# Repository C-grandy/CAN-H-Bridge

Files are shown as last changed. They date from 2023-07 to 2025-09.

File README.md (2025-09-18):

# CAN-H-Bridge
A CAN Bus controlled H-Bridge motor driver designed for 12V, 10-20A brushed motors with encoders. Features a Atmel Atmega328 MCU along with a MCP2515 CAN controller for compatability with Arduino or standalone AVR C. 
NOTE: This design should not be used as is, it has a few design flaws as it was a proof of concept that was never developed further. 
## Circuit Overview
The design has two major parts, the controls and the H-Bridge motor driver. 
### Controls
The heart of the control system is the Atmega328 MCU. This MCU communicates over CAN for connectivity to other devices along with sending the appropriate PWM and enable signals to the H-bridge driver. It has connectors for a 2 pin quadrature encoder, specifically designed with GoBilda Yellow Jacket gear motors in mind. 


### Driver
The driver features 2 IRS2104's half-bridge gate drivers to drive the IRF3205 MOSFETS. This is a standard H-bridge setup, with adequete protection for expected loads. 
NOTE: This circuit uses a external 12V refrence for the IRS2104 input voltage, do not exceed 12V on board VCC or the driver might not work correctly. This is a major design flaw in the circuit as it should include a isolated supply that is refrenced off of VCC. 


## PCB Layout:
This board is a 2 layer stackup, with very basic PCB design rules followed. The overall design of the PCB is lacking, the traces are not properly sized for the loads at hand and a lack of copper pours makes this a elementary design. Even with these shortcomings, the PCB works as expected, but in long tests proved it needed refinement. 

Front: 


Back: 


### 3D Render: 

Front:



Back:



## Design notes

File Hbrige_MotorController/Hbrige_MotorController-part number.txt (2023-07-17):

"Source:","C:\Users\rober\Desktop\Hbrige_MotorController\Hbrige_MotorController.kicad_sch"
"Date:","7/16/2023 10:04:55 PM"
"Tool:","Eeschema (6.0.8)"
"Generator:","D:\KiCad\6.0\bin\scripting\plugins/bom_csv_grouped_by_value.py"
"Component Count:","62"

"Individual Components:"

"Item","Qty","Reference(s)","Value","LibPart","Footprint","Datasheet"

"","","D11","LED_G","Device:LED","LED_SMD:LED_0603_1608Metric_Pad1.05x0.95mm_HandSolder","~"
"","","D12","LED_R","Device:LED","LED_SMD:LED_0603_1608Metric_Pad1.05x0.95mm_HandSolder","~"

"","","J1","Conn_01x05_Female","Connector:Conn_01x05_Female","Connector_JST:JST_XH_B5B-XH-A_1x05_P2.50mm_Vertical","~"
"","","J2","Conn_01x04_Female","Connector:Conn_01x04_Female","Connector_JST:JST_XA_B04B-XASK-1-A_1x04_P2.50mm_Vertical","~"
"","","J3","Conn_01x04_Female","Connector:Conn_01x04_Female","Connector_JST:JST_XA_B04B-XASK-1-A_1x04_P2.50mm_Vertical","~"
"","","J4","Conn_02x03_Odd_Even","Connector_Generic:Conn_02x03_Odd_Even","Connector_PinHeader_2.54mm:PinHeader_2x03_P2.54mm_Vertical","~"
"","","J5","Screw_Terminal_01x02","Connector:Screw_Terminal_01x02","TerminalBlock:TerminalBlock_Altech_AK300-2_P5.00mm","~"

"","","M1","Motor_DC","Motor:Motor_DC","TerminalBlock:TerminalBlock_Altech_AK300-2_P5.00mm","~"

"","","Q1","IRF3205","Transistor_FET:IRF3205","Package_TO_SOT_THT:TO-220-3_Horizontal_TabDown","http://www.irf.com/product-info/datasheets/data/irf3205.pdf"
"","","Q2","IRF3205","Transistor_FET:IRF3205","Package_TO_SOT_THT:TO-220-3_Horizontal_TabDown","http://www.irf.com/product-info/datasheets/data/irf3205.pdf"
"","","Q3","IRF3205","Transistor_FET:IRF3205","Package_TO_SOT_THT:TO-220-3_Horizontal_TabDown","http://www.irf.com/product-info/datasheets/data/irf3205.pdf"
"","","Q4","IRF3205","Transistor_FET:IRF3205","Package_TO_SOT_THT:TO-220-3_Horizontal_TabDown","http://www.irf.com/product-info/datasheets/data/irf3205.pdf"

"","","R1","1K","Device:R","Resistor_SMD:R_0603_1608Metric_Pad0.98x0.95mm_HandSolder","~"
"","","R2","1K","Device:R","Resistor_SMD:R_0603_1608Metric_Pad0.98x0.95mm_HandSolder","~"
"","","R3","1K","Device:R","Resistor_SMD:R_0603_1608Metric_Pad0.98x0.95mm_HandSolder","~"
"","","R4","10K","Device:R","Resistor_SMD:R_0603_1608Metric_Pad0.98x0.95mm_HandSolder","~"
"","","R5","27k","Device:R","Resistor_SMD:R_0603_1608Metric_Pad0.98x0.95mm_HandSolder","~"
"","","R6","27k","Device:R","Resistor_SMD:R_0603_1608Metric_Pad0.98x0.95mm_HandSolder","~"
"","","R7","27k","Device:R","Resistor_SMD:R_0603_1608Metric_Pad0.98x0.95mm_HandSolder","~"
"","","R8","27k","Device:R","Resistor_SMD:R_0603_1608Metric_Pad0.98x0.95mm_HandSolder","~"
"","","R9","1k","Device:R","Resistor_SMD:R_0603_1608Metric_Pad0.98x0.95mm_HandSolder","~"
"","","R10","1k","Device:R","Resistor_SMD:R_0603_1608Metric_Pad0.98x0.95mm_HandSolder","~"
"","","R11","1k","Device:R","Resistor_SMD:R_0603_1608Metric_Pad0.98x0.95mm_HandSolder","~"
"","","R12","k5","Device:R","Resistor_SMD:R_0603_1608Metric_Pad0.98x0.95mm_HandSolder","~"
"","","R13","1K","Device:R","Resistor_SMD:R_0603_1608Metric_Pad0.98x0.95mm_HandSolder","~"
"","","R14","1K","Device:R","Resistor_SMD:R_0603_1608Metric_Pad0.98x0.95mm_HandSolder","~"
"","","R15","120","Device:R","Resistor_SMD:R_0603_1608Metric_Pad0.98x0.95mm_HandSolder","~"

"","","U1","ATmega328P-A","MCU_Microchip_ATmega:ATmega328P-A","Package_QFP:TQFP-32_7x7mm_P0.8mm","http://ww1.microchip.com/downloads/en/DeviceDoc/ATmega328_P%20AVR%20MCU%20with%20picoPower%20Technology%20Data%20Sheet%2040001984A.pdf"
"","","U2","MCP2515-xSO","Interface_CAN_LIN:MCP2515-xSO","Package_SO:SOIC-18W_7.5x11.6mm_P1.27mm","http://ww1.microchip.com/downloads/en/DeviceDoc/21801e.pdf"
"","","U3","MCP2551-I-SN","Interface_CAN_LIN:MCP2551-I-SN","Package_SO:SOIC-8_3.9x4.9mm_P1.27mm","http://ww1.microchip.com/downloads/en/devicedoc/21667d.pdf"
"","","U4","IRS2104","Driver_FET:IR2104","Package_SO:SOIC-8_3.9x4.9mm_P1.27mm","https://www.infineon.com/dgdl/ir2104.pdf?fileId=5546d462533600a4015355c7c1c31671"
"","","U5","IRS2104","Driver_FET:IR2104","Package_SO:SOIC-8_3.9x4.9mm_P1.27mm","https://www.infineon.com/dgdl/ir2104.pdf?fileId=5546d462533600a4015355c7c1c31671"

"","","Y1","8MHz","Device:Crystal","Crystal:Crystal_SMD_5032-2Pin_5.0x3.2mm","~"
"","","Y2","16MHz","Device:Crystal","Crystal:Crystal_SMD_5032-2Pin_5.0x3.2mm","~"

"Collated Components:"

"Item","Qty","Reference(s)","Value","LibPart","Footprint","Datasheet"
"1","3","C1, C11, C12","10uf 16V","Device:C_Polarized","Capacitor_THT:CP_Radial_D5.0mm_P2.00mm","~"
"2","4","C2, C3, C14, C19","1uf","Device:C","Resistor_SMD:R_0603_1608Metric_Pad0.98x0.95mm_HandSolder","~"
"3","1","C4","100nf","Device:C","Resistor_SMD:R_0603_1608Metric_Pad0.98x0.95mm_HandSolder","~"
"4","2","C5, C6","22pf","Device:C","Capacitor_SMD:C_0603_1608Metric_Pad1.08x0.95mm_HandSolder","~"
"5","2","C7, C8","22pf","Device:C","Resistor_SMD:R_0603_1608Metric_Pad0.98x0.95mm_HandSolder","~"
"6","1","C9",".1uf","Device:C","Capacitor_SMD:C_0603_1608Metric_Pad1.08x0.95mm_HandSolder","~"
"7","1","C10",".1uf","Device:C","Resistor_SMD:R_0603_1608Metric_Pad0.98x0.95mm_HandSolder","~"
"8","4","C13, C15, C17, C18","470nf","Device:C","Resistor_SMD:R_0603_1608Metric_Pad0.98x0.95mm_HandSolder","~"
"9","6","D1, D4, D7, D8, D9, D10","1N5819","Diode:1N5819","Diode_SMD:D_SOD-123","http://www.vishay.com/docs/88525/1n5817.pdf"
"10","4","D2, D3, D5, D6","1N4148","Diode:1N4148","Diode_SMD:D_SOD-523","https://assets.nexperia.com/documents/data-sheet/1N4148_1N4448.pdf"
"11","1","D11","LED_G","Device:LED","LED_SMD:LED_0603_1608Metric_Pad1.05x0.95mm_HandSolder","~"
"12","1","D12","LED_R","Device:LED","LED_SMD:LED_0603_1608Metric_Pad1.05x0.95mm_HandSolder","~"
"13","1","J1","Conn_01x05_Female","Connector:Conn_01x05_Female","Connector_JST:JST_XH_B5B-XH-A_1x05_P2.50mm_Vertical","~"
"14","2","J2, J3","Conn_01x04_Female","Connector:Conn_01x04_Female","Connector_JST:JST_XA_B04B-XASK-1-A_1x04_P2.50mm_Vertical","~"
"15","1","J4","Conn_02x03_Odd_Even","Connector_Generic:Conn_02x03_Odd_Even","Connector_PinHeader_2.54mm:PinHeader_2x03_P2.54mm_Vertical","~"
"16","1","J5","Screw_Terminal_01x02","Connector:Screw_Terminal_01x02","TerminalBlock:TerminalBlock_Altech_AK300-2_P5.00mm","~"
"17","1","M1","Motor_DC","Motor:Motor_DC","TerminalBlock:TerminalBlock_Altech_AK300-2_P5.00mm","~"
"18","4","Q1, Q2, Q3, Q4","IRF3205","Transistor_FET:IRF3205","Package_TO_SOT_THT:TO-220-3_Horizontal_TabDown","http://www.irf.com/product-info/datasheets/data/irf3205.pdf"
"19","5","R1, R2, R3, R13, R14","1K","Device:R","Resistor_SMD:R_0603_1608Metric_Pad0.98x0.95mm_HandSolder","~"
"20","1","R4","10K","Device:R","Resistor_SMD:R_0603_1608Metric_Pad0.98x0.95mm_HandSolder","~"
"21","4","R5, R6, R7, R8","27k","Device:R","Resistor_SMD:R_0603_1608Metric_Pad0.98x0.95mm_HandSolder","~"
"22","3","R9, R10, R11","1k","Device:R","Resistor_SMD:R_0603_1608Metric_Pad0.98x0.95mm_HandSolder","~"
"23","1","R12","k5","Device:R","Resistor_SMD:R_0603_1608Metric_Pad0.98x0.95mm_HandSolder","~"
"24","1","R15","120","Device:R","Resistor_SMD:R_0603_1608Metric_Pad0.98x0.95mm_HandSolder","~"
"25","1","U1","ATmega328P-A","MCU_Microchip_ATmega:ATmega328P-A","Package_QFP:TQFP-32_7x7mm_P0.8mm","http://ww1.microchip.com/downloads/en/DeviceDoc/ATmega328_P%20AVR%20MCU%20with%20picoPower%20Technology%20Data%20Sheet%2040001984A.pdf"
"26","1","U2","MCP2515-xSO","Interface_CAN_LIN:MCP2515-xSO","Package_SO:SOIC-18W_7.5x11.6mm_P1.27mm","http://ww1.microchip.com/downloads/en/DeviceDoc/21801e.pdf"
"27","1","U3","MCP2551-I-SN","Interface_CAN_LIN:MCP2551-I-SN","Package_SO:SOIC-8_3.9x4.9mm_P1.27mm","http://ww1.microchip.com/downloads/en/devicedoc/21667d.pdf"
"28","2","U4, U5","IRS2104","Driver_FET:IR2104","Package_SO:SOIC-8_3.9x4.9mm_P1.27mm","https://www.infineon.com/dgdl/ir2104.pdf?fileId=5546d462533600a4015355c7c1c31671"
"29","1","Y1","8MHz","Device:Crystal","Crystal:Crystal_SMD_5032-2Pin_5.0x3.2mm","~"
"30","1","Y2","16MHz","Device:Crystal","Crystal:Crystal_SMD_5032-2Pin_5.0x3.2mm","~"

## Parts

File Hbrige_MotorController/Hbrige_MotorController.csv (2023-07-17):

Id | Designator | Package | Quantity | Designation | Supplier and ref
1 | C19,C14,C3,C2 | C_0603_1608Metric_Pad1.08x0.95mm_HandSolder | 4 | 1uf
2 | C18,C17,C15,C13 | C_0603_1608Metric_Pad1.08x0.95mm_HandSolder | 4 | 470nf
3 | C10,C4,C9 | C_0603_1608Metric_Pad1.08x0.95mm_HandSolder | 3 | .1uf
4 | C8,C7,C5,C6 | C_0603_1608Metric_Pad1.08x0.95mm_HandSolder | 4 | 22pf
5 | D12 | LED_0603_1608Metric_Pad1.05x0.95mm_HandSolder | 1 | LED_R
6 | M1 | TerminalBlock_Altech_AK300-2_P5.00mm | 1 | Motor_DC
7 | U2 | SOIC-18W_7.5x11.6mm_P1.27mm | 1 | MCP2515-xSO
8 | R3,R13,R2,R1,R14 | R_0603_1608Metric_Pad0.98x0.95mm_HandSolder | 5 | 1K
9 | ,,, | MountingHole_3.2mm_M3 | 4 | MountingHole
10 | Y2 | Crystal_SMD_5032-2Pin_5.0x3.2mm | 1 | 16MHz
11 | J4 | PinHeader_2x03_P2.54mm_Vertical | 1 | Conn_02x03_Odd_Even
12 | R15 | R_0603_1608Metric_Pad0.98x0.95mm_HandSolder | 1 | 120
13 | J2,J3 | JST_XA_B04B-XASK-1-A_1x04_P2.50mm_Vertical | 2 | Conn_01x04_Female
14 | Y1 | Crystal_SMD_5032-2Pin_5.0x3.2mm | 1 | 8MHz
15 | J1 | JST_XH_B5B-XH-A_1x05_P2.50mm_Vertical | 1 | Conn_01x05_Female
16 | J5 | TerminalBlock_Altech_AK300-2_P5.00mm | 1 | Screw_Terminal_01x02
17 | U1 | TQFP-32_7x7mm_P0.8mm | 1 | ATmega328P-A
18 | U3 | SOIC-8_3.9x4.9mm_P1.27mm | 1 | MCP2551-I-SN
19 | D11 | LED_0603_1608Metric_Pad1.05x0.95mm_HandSolder | 1 | LED_G
20 | C11,C1,C12 | CP_Radial_D5.0mm_P2.00mm | 3 | 10uf 16V
21 | R4 | R_0603_1608Metric_Pad0.98x0.95mm_HandSolder | 1 | 10K
22 | R10,R11,R9 | R_0603_1608Metric_Pad0.98x0.95mm_HandSolder | 3 | 1k
23 | D8,D4,D10,D7,D9,D1 | D_SOD-123 | 6 | 1N5819
24 | Q3,Q1,Q4,Q2 | TO-220-3_Horizontal_TabDown | 4 | IRF3205
25 | R7,R8,R5,R6 | R_0603_1608Metric_Pad0.98x0.95mm_HandSolder | 4 | 27k
26 | D2,D3,D5,D6 | D_SOD-523 | 4 | 1N4148
27 | R12 | R_0603_1608Metric_Pad0.98x0.95mm_HandSolder | 1 | k5
28 | U5,U4 | SOIC-8_3.9x4.9mm_P1.27mm | 2 | IRS2104

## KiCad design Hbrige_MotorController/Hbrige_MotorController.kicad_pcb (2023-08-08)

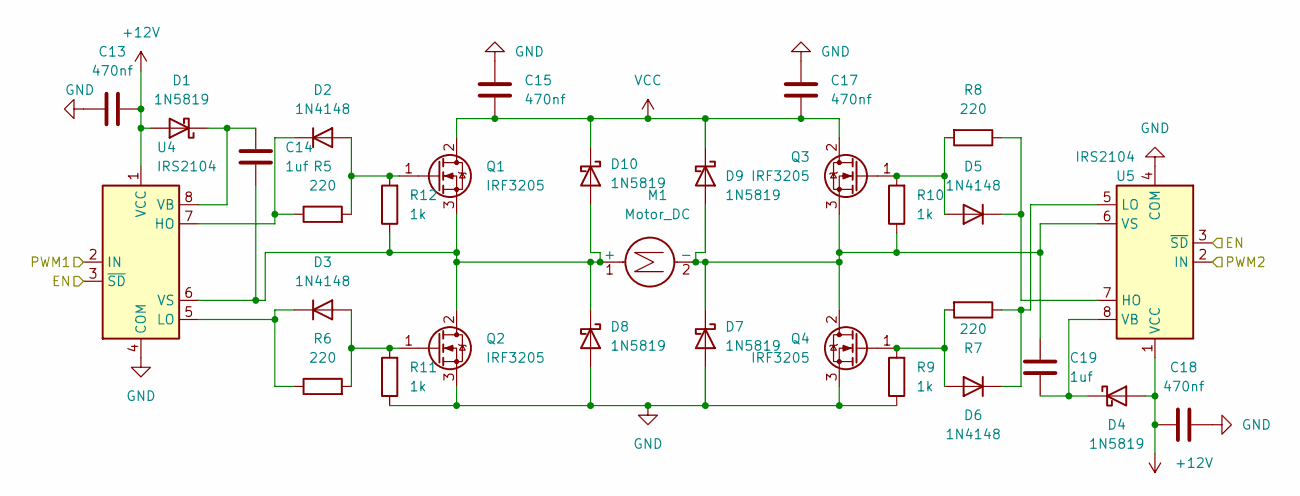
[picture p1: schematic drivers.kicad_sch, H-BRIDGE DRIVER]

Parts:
C13, C15, C17, C18: 470nf; C_0603_1608Metric_Pad1.08x0.95mm_HandSolder
C14, C19: 1uf; C_0603_1608Metric_Pad1.08x0.95mm_HandSolder
D1, D4, D7, D8, D9, D10: 1N5819; D_SOD-123
D2, D3, D5, D6: 1N4148; D_SOD-523
M1: Motor_DC; TerminalBlock_Altech_AK300-2_P5.00mm
Q1, Q2, Q3, Q4: IRF3205; TO-220-3_Horizontal_TabDown
R5, R6, R7, R8: 220; R_0603_1608Metric_Pad0.98x0.95mm_HandSolder
R9, R10, R11, R12: 1k; R_0603_1608Metric_Pad0.98x0.95mm_HandSolder
U4, U5: IRS2104; SOIC-8_3.9x4.9mm_P1.27mm

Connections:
+12V: C13.1, C18.2, D1.2 (A), D4.2 (A), U4.1 (VCC), U5.1 (VCC); also elsewhere on the board
/Controls/EN: U4.3 (~SD), U5.3 (~SD); also elsewhere on the board
/Controls/PWM1: U4.2 (IN); also elsewhere on the board
/Controls/PWM2: U5.2 (IN); also elsewhere on the board
GND: C13.2, C15.2, C17.2, C18.1, D7.2 (A), D8.2 (A), Q2.3 (S), Q4.3 (S), R9.1, R11.1, U4.4 (COM), U5.4 (COM); also elsewhere on the board
unnamed: C14.1, D1.1 (K), U4.8 (VB)
unnamed: C14.2, D8.1 (K), D10.2 (A), M1.1 (+), Q1.3 (S), Q2.2 (D), R12.1, U4.6 (VS)
unnamed: C19.1, D4.1 (K), U5.8 (VB)
unnamed: C19.2, D7.1 (K), D9.2 (A), M1.2 (-), Q3.3 (S), Q4.2 (D), R10.1, U5.6 (VS)
unnamed: D2.1 (K), R5.1, U4.7 (HO)
unnamed: D2.2 (A), Q1.1 (G), R5.2, R12.2
unnamed: D3.1 (K), R6.1, U4.5 (LO)
unnamed: D3.2 (A), Q2.1 (G), R6.2, R11.2
unnamed: D5.1 (K), R8.1, U5.7 (HO)
unnamed: D5.2 (A), Q3.1 (G), R8.2, R10.2
unnamed: D6.1 (K), R7.1, U5.5 (LO)
unnamed: D6.2 (A), Q4.1 (G), R7.2, R9.2
VCC: C15.1, C17.1, D9.1 (K), D10.1 (K), Q1.2 (D), Q3.2 (D); also elsewhere on the board

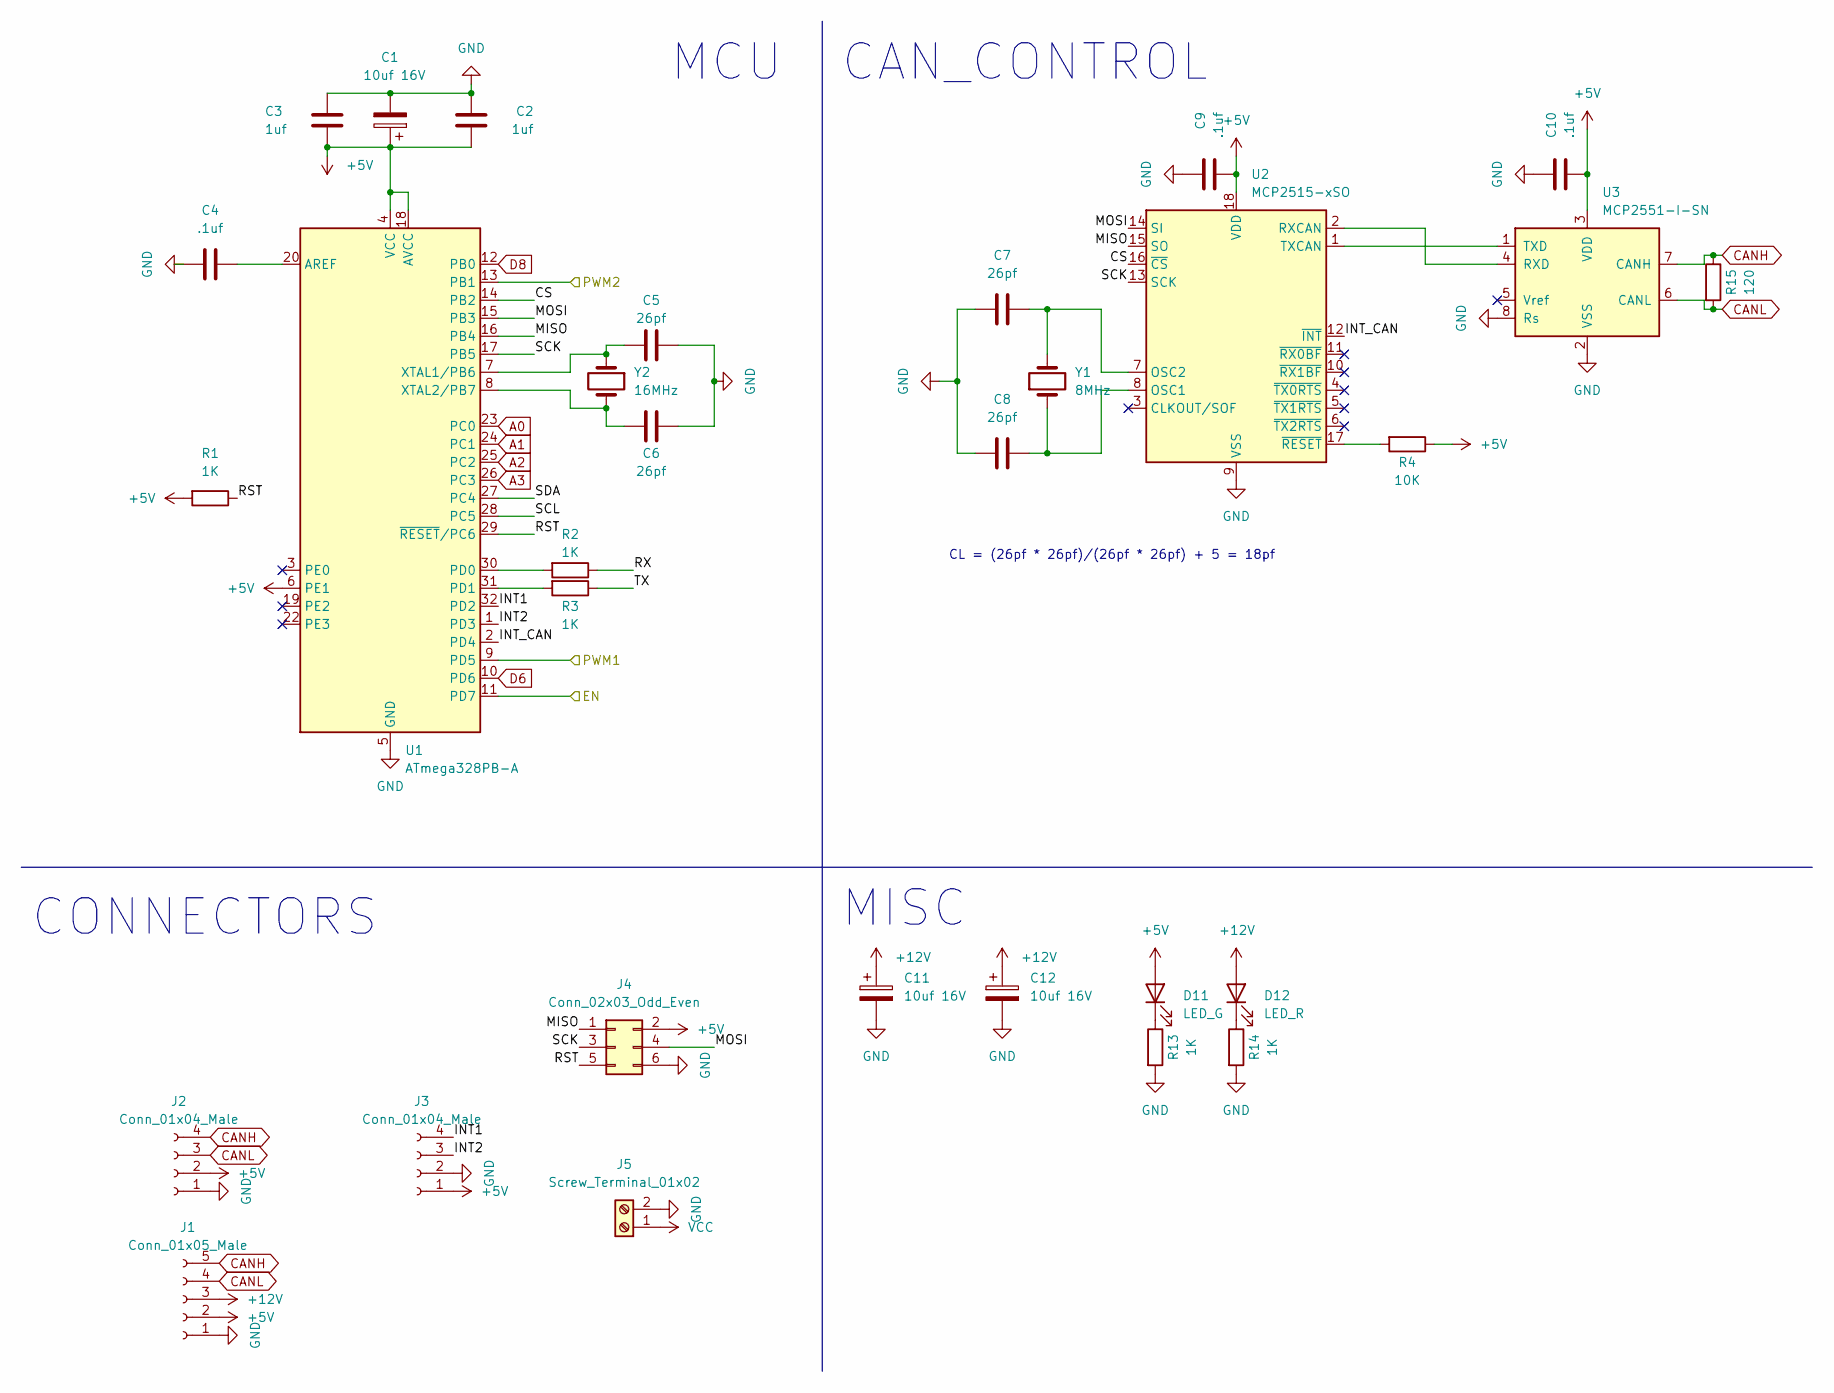
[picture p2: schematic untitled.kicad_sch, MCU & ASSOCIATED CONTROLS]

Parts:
C1, C11, C12: 10uf 16V; CP_Radial_D5.0mm_P2.00mm
C2, C3: 1uf; C_0603_1608Metric_Pad1.08x0.95mm_HandSolder
C4, C9, C10: .1uf; C_0603_1608Metric_Pad1.08x0.95mm_HandSolder
C5, C6, C7, C8: 26pf; C_0603_1608Metric_Pad1.08x0.95mm_HandSolder
D11: LED_G; LED_0603_1608Metric_Pad1.05x0.95mm_HandSolder
D12: LED_R; LED_0603_1608Metric_Pad1.05x0.95mm_HandSolder
J1: Conn_01x05_Male; JST_XH_B5B-XH-A_1x05_P2.50mm_Vertical
J2, J3: Conn_01x04_Male; JST_XA_B04B-XASK-1-A_1x04_P2.50mm_Vertical
J4: Conn_02x03_Odd_Even; PinHeader_2x03_P2.54mm_Vertical
J5: Screw_Terminal_01x02; TerminalBlock_Altech_AK300-2_P5.00mm
R1, R2, R3, R13, R14: 1K; R_0603_1608Metric_Pad0.98x0.95mm_HandSolder
R4: 10K; R_0603_1608Metric_Pad0.98x0.95mm_HandSolder
R15: 120; R_0603_1608Metric_Pad0.98x0.95mm_HandSolder
U1: ATmega328PB-A; TQFP-32_7x7mm_P0.8mm
U2: MCP2515-xSO; SOIC-18W_7.5x11.6mm_P1.27mm
U3: MCP2551-I-SN; SOIC-8_3.9x4.9mm_P1.27mm
Y1: 8MHz; Crystal_SMD_5032-2Pin_5.0x3.2mm
Y2: 16MHz; Crystal_SMD_5032-2Pin_5.0x3.2mm

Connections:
+5V: C1.1, C2.2, C3.1, C9.2, C10.2, D11.2 (A), J1.2, J2.2, J3.1, J4.2, R1.2, R4.1, U1.4 (VCC), U1.6 (PE1), U1.18 (AVCC), U2.18 (VDD), U3.3 (VDD)
+12V: C11.1, C12.1, D12.2 (A), J1.3; also elsewhere on the board
/Controls/CS: U1.14 (PB2), U2.16 (~CS)
/Controls/EN: U1.11 (PD7); also elsewhere on the board
/Controls/INT1: J3.4, U1.32 (PD2)
/Controls/INT2: J3.3, U1.1 (PD3)
/Controls/INT_CAN: U1.2 (PD4), U2.12 (~INT)
/Controls/MISO: J4.1, U1.16 (PB4), U2.15 (SO)
/Controls/MOSI: J4.4, U1.15 (PB3), U2.14 (SI)
/Controls/PWM1: U1.9 (PD5); also elsewhere on the board
/Controls/PWM2: U1.13 (PB1); also elsewhere on the board
/Controls/RST: J4.5, R1.1, U1.29 (~RESET/PC6)
/Controls/RX: R2.1
/Controls/SCK: J4.3, U1.17 (PB5), U2.13 (SCK)
/Controls/SCL: U1.28 (PC5)
/Controls/SDA: U1.27 (PC4)
/Controls/TX: R3.1
A0: U1.23 (PC0)
A1: U1.24 (PC1)
A2: U1.25 (PC2)
A3: U1.26 (PC3)
CANH: J1.5, J2.4, R15.1, U3.7 (CANH)
CANL: J1.4, J2.3, R15.2, U3.6 (CANL)
D6: U1.10 (PD6)
D8: U1.12 (PB0)
GND: C1.2, C2.1, C3.2, C4.1, C5.1, C6.1, C7.1, C8.1, C9.1, C10.1, C11.2, C12.2, J1.1, J2.1, J3.2, J4.6, J5.2, R13.2, R14.2, U1.5 (GND), U1.21 (GND), U2.9 (VSS), U3.2 (VSS), U3.8 (Rs); also elsewhere on the board
unnamed: C4.2, U1.20 (AREF)
unnamed: C5.2, U1.7 (XTAL1/PB6), Y2.1
unnamed: C6.2, U1.8 (XTAL2/PB7), Y2.2
unnamed: C7.2, U2.7 (OSC2), Y1.2
unnamed: C8.2, U2.8 (OSC1), Y1.1
unnamed: D11.1 (K), R13.1
unnamed: D12.1 (K), R14.1
unnamed: R2.2, U1.30 (PD0)
unnamed: R3.2, U1.31 (PD1)
unnamed: R4.2, U2.17 (~RESET)
unnamed: U2.1 (TXCAN), U3.1 (TXD)
unnamed: U2.2 (RXCAN), U3.4 (RXD)
VCC: J5.1; also elsewhere on the board

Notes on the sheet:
MCU
CONNECTORS
CL = (26pf * 26pf)/(26pf * 26pf) + 5 = 18pf
CAN_CONTROL
MISC

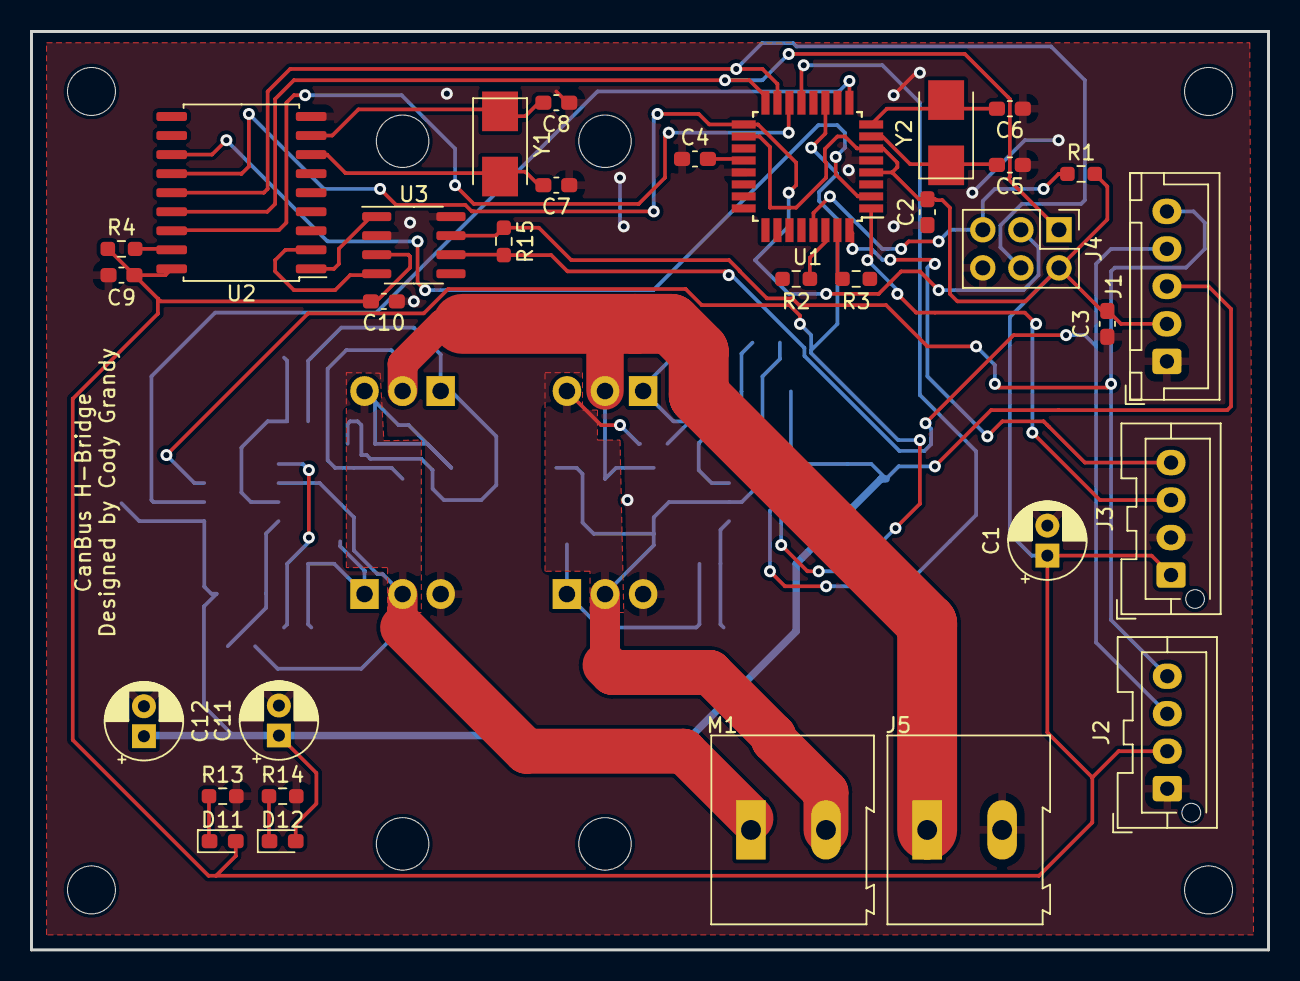
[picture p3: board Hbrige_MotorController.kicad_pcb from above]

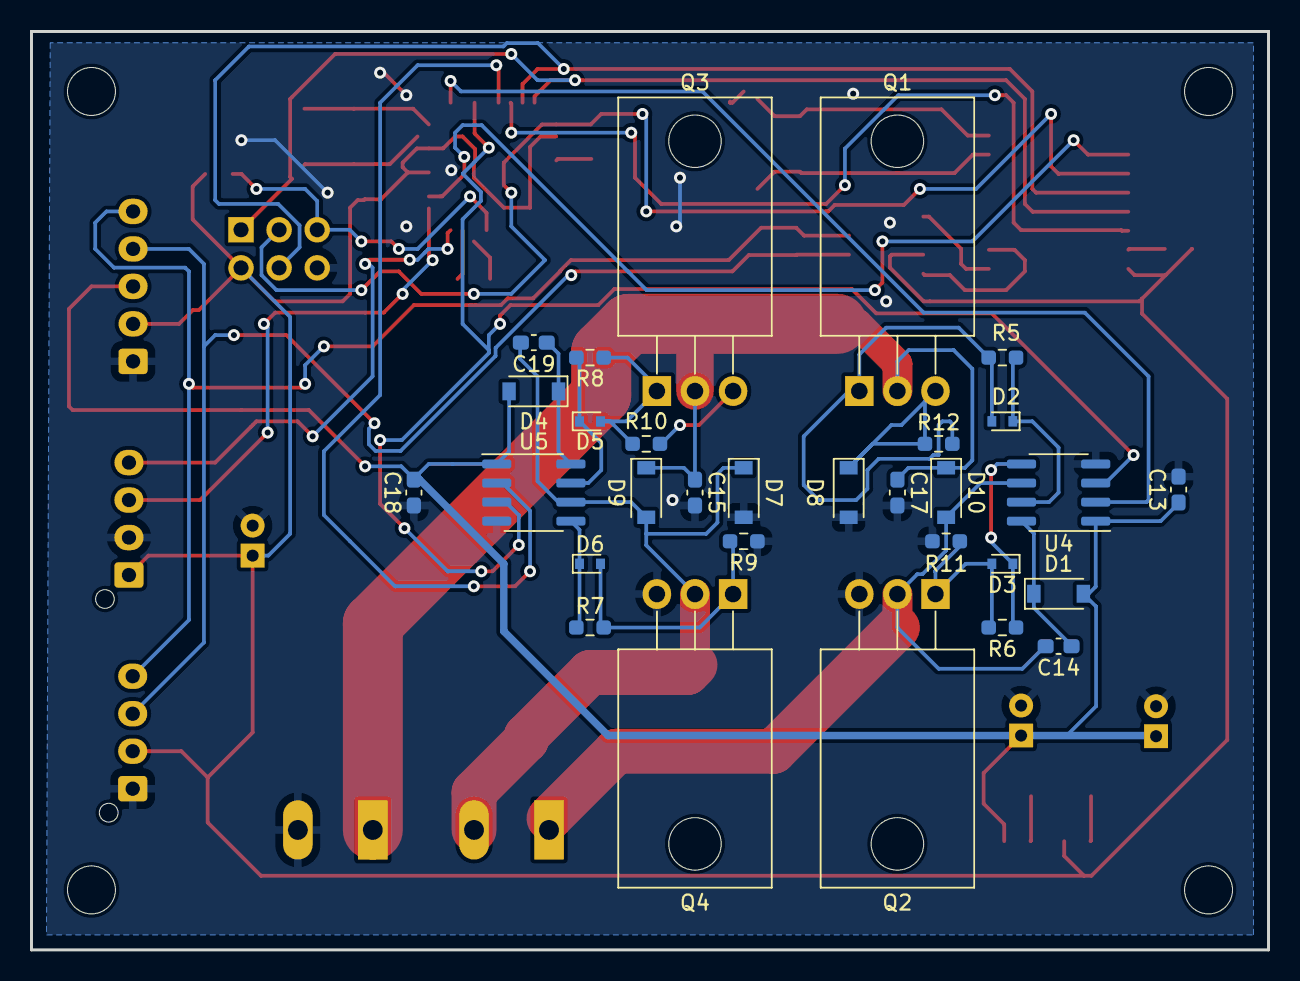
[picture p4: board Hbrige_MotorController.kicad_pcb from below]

Board: 2 copper layers, 82.5 x 61.2 mm, 62 parts (30 on the bottom side), 41 nets.
